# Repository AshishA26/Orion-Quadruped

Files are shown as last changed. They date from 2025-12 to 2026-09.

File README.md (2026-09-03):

# Orion — ROS2 Quadruped Robot

A custom-built 12-DOF quadruped robot designed, built, and programmed from scratch over 8 months. Uses an NVIDIA Jetson Orin Nano for high-level AI and perception, and a custom STM32 PCB for real-time low-level control.

Check out the [Demo Video](https://youtu.be/wUXvWBjLTyA)!

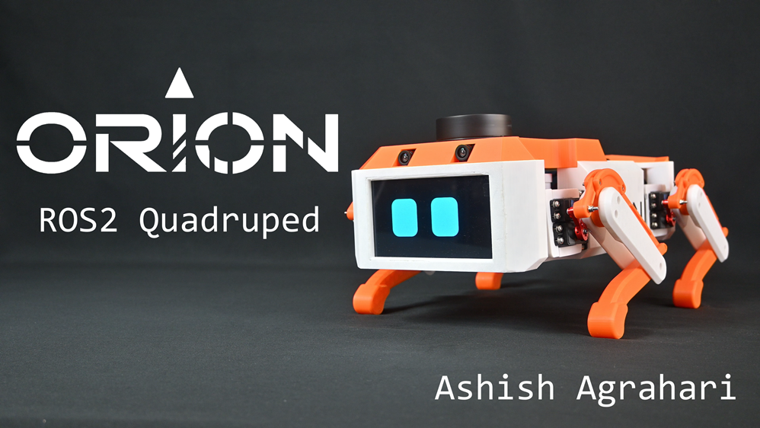
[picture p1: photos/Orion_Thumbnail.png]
Orion


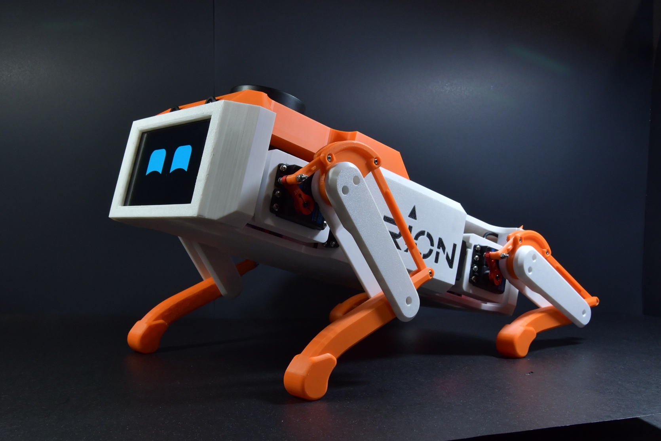
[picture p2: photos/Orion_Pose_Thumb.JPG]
Orion Pose


## Key Features

- **ROS2 / AI** — Isaac ROS Docker on Jetson Orin Nano, TensorRT for accelerated inference
- **Perception** — Stereo depth (MIDAS, SGBM) via dual CSI cameras + MediaPipe hand-pose recognition
- **SLAM & Autonomy** — RPLIDAR A1M8 with `slam_toolbox` and `nav2` for mapping and point-and-click pure-pursuit navigation
- **Embedded Control** — Custom STM32 FreeRTOS firmware: IK, walking gaits, IMU-based stabilization
- **Custom PCBs** — Multi-layer SMD boards for power distribution, servo actuation, and sensor interfacing
- **RL / Sim** — PPO training (RSL RL) in NVIDIA Isaac Lab, flat and rough terrain environments
- **Robot Eyes** — Expressive OLED eye animations via a custom Python/OpenCV node

---

## Software Architecture

**[Jetson — Isaac ROS Workspace](./Software/Jetson/workspace/isaac_ros-dev/README.md)**

| Package | Description |
|:---|:---|
| `orion_base` | STM32 UART bridge, joystick parser, command mux, robot eyes, joint state republisher |
| `orion_camera` | Dual CSI GStreamer node, MIDAS/SGBM depth, MediaPipe hand pose |
| `orion_lidar` | RPLIDAR A1M8 driver, `slam_toolbox` |
| `orion_navigation` | `nav2`, Pure-Pursuit path following |
| `orion_bringup` | Launch files, Docker config, systemd auto-start |
| `orion_msgs` | Custom messages: motion cmd, eye cmd, battery voltage, IMU, leg info |
| `orion_urdf` | URDF model with SolidWorks meshes, RViz launch |

**[STM32](./Software/STM32Firmware/README.md) · [Orion Firmware](./Software/STM32Firmware/Orion/README.md)**

- 5 FreeRTOS tasks: Real-time IK & gait control (Realtime) with 3-DOF per leg and 6-DOF body posture control, UART RX/TX with Jetson via DMA (High/Normal), IMU reading, Battery monitoring.

**[Reinforcement Learning](./Software/reinforcement-learning/README.md)**

- PPO training in Isaac Lab with flat and rough terrain environments. 
- SolidWorks → URDF → USD pipeline.

---

### Software Gallery

| LiDAR SLAM | Autonomous Navigation |
| :---: | :---: |
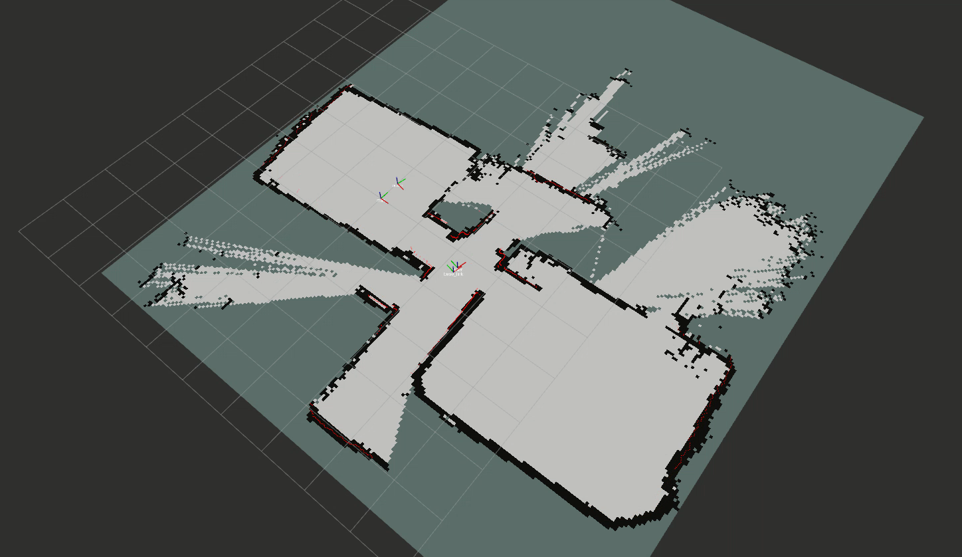
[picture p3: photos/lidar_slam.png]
SLAM
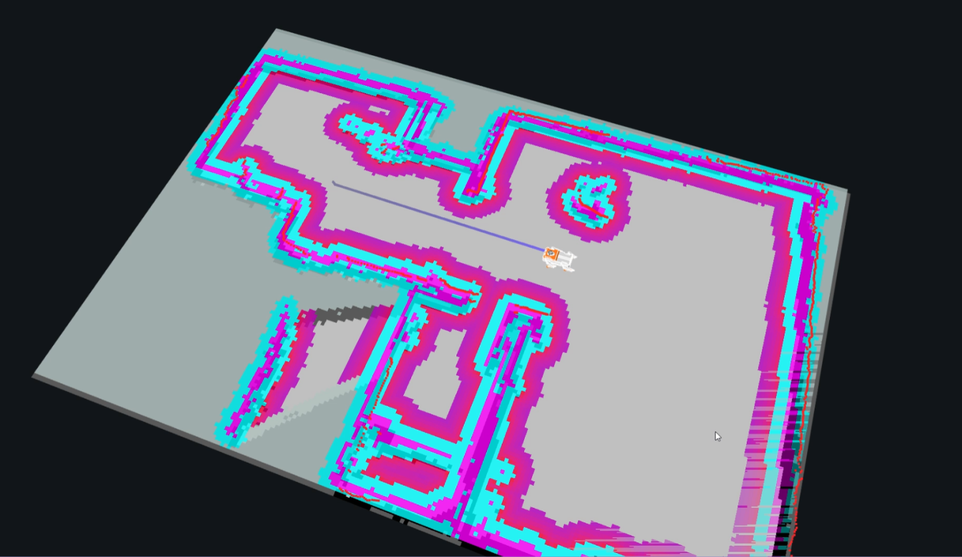
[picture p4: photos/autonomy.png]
Autonomy
|  |  |
| Original Camera Feed | TensorRT Depth Map |
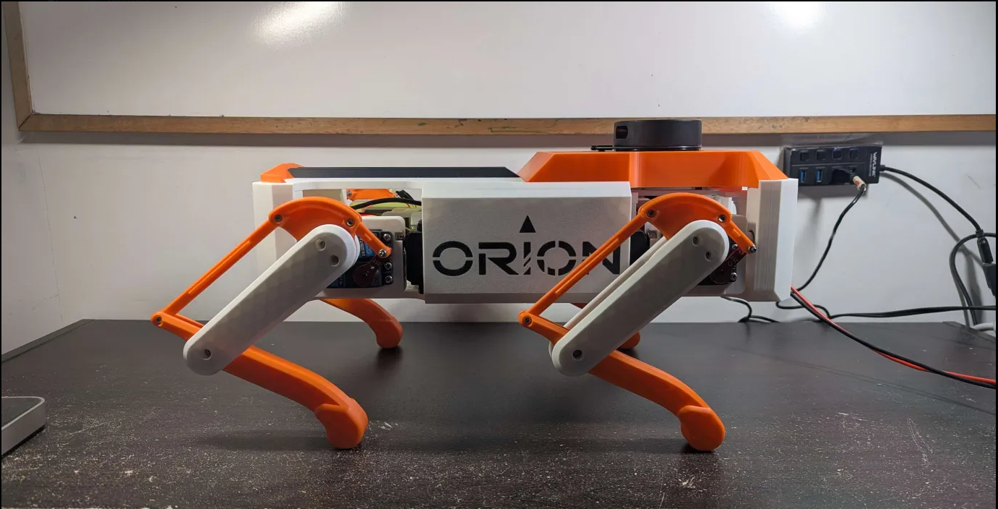
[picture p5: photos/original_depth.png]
Original Image
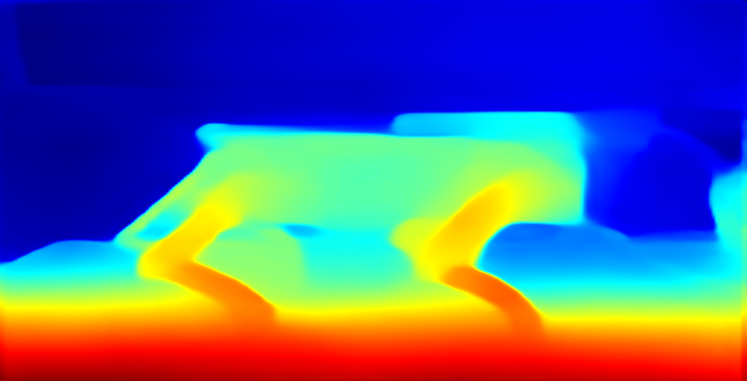
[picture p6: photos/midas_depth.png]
Depth Map
|  |  |
| Hand Pose Detection | Reinforcement Learning in Isaac Lab |
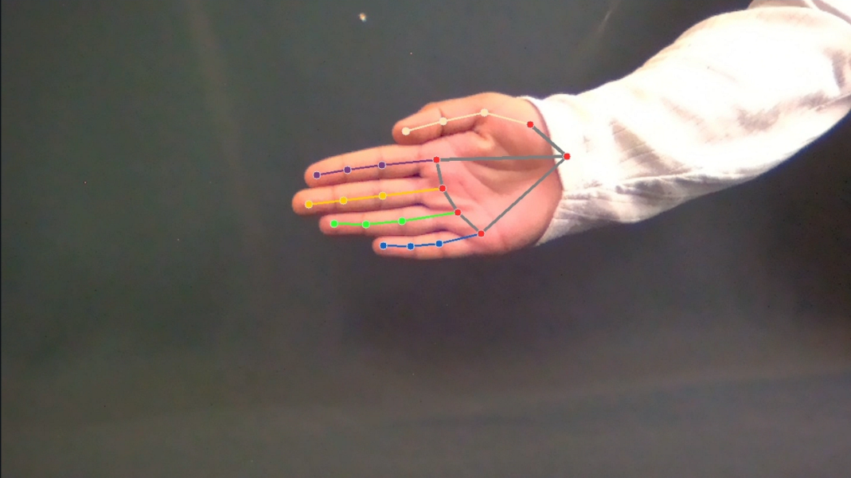
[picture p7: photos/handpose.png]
Hand Pose Recognition
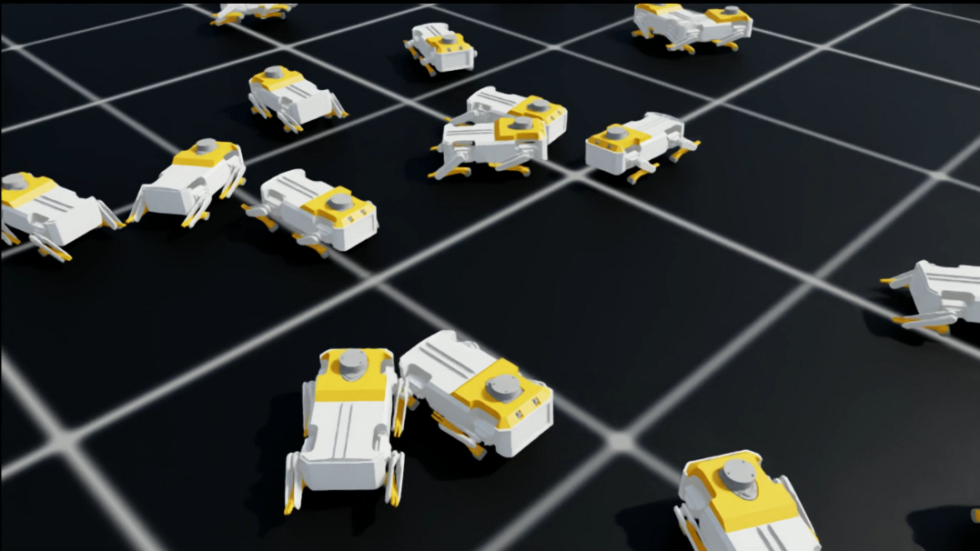
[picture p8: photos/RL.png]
Reinforcement Learning
|  |  |

<p align="center">
    <strong>Foxglove Dashboard</strong>
</p>

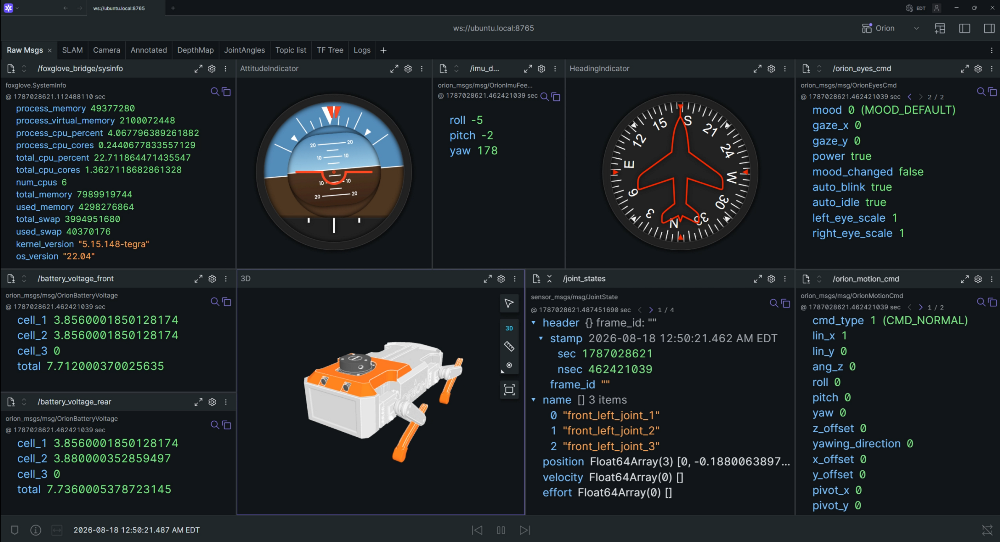
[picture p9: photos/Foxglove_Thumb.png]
Foxglove Dashboard


---

## Electrical & Electronics

Custom multi-layer KiCad PCBs, fully SMD-assembled. Multiple I2C buses with LTC4311 active termination, extensive test pads and debug headers.

- **Control Board** — STM32F401, BNO055 IMU, PCA9685 servo driver
- **Power Board** — Battery distribution, INA3221 voltage monitoring (3 rails), high-current servo lines, battery alarm

### Electrical Gallery
| Control Board | Power Board |
| :---: | :---: |
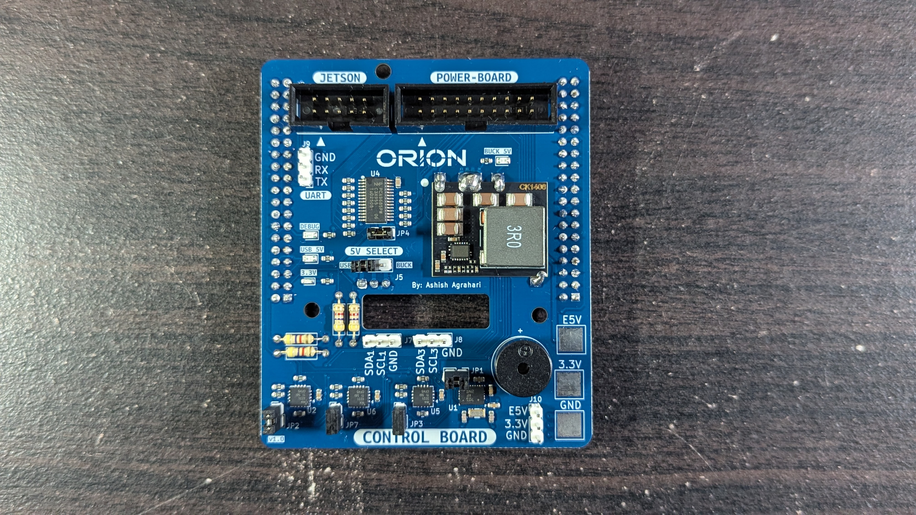
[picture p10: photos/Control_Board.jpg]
Control board
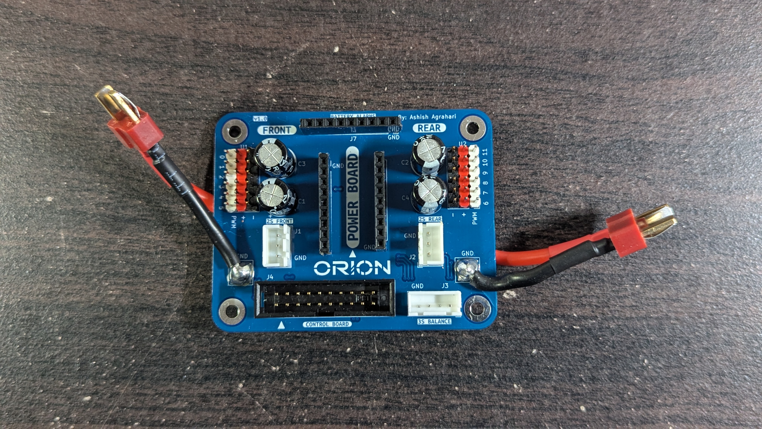
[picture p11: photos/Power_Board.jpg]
Power board
|  |  |

| Control Board | Control Board Compute | Power Board |
| :---: | :---: | :---: |
| Control board schematic | Compute schematic | Power Board schematic |

---

## Mechanical Design

Chassis iteratively modelled in SolidWorks. 3D printed with 2-part silicone injection-molded feet. Bearings in all 12 joints. Magnetic mounts for tool-free access to internal electronics. Single-leg linear-rail test jig used to validate IK and gait before full integration.

| Main body parts | Leg Assembly & Silicone Feet |
| :---: | :---: |
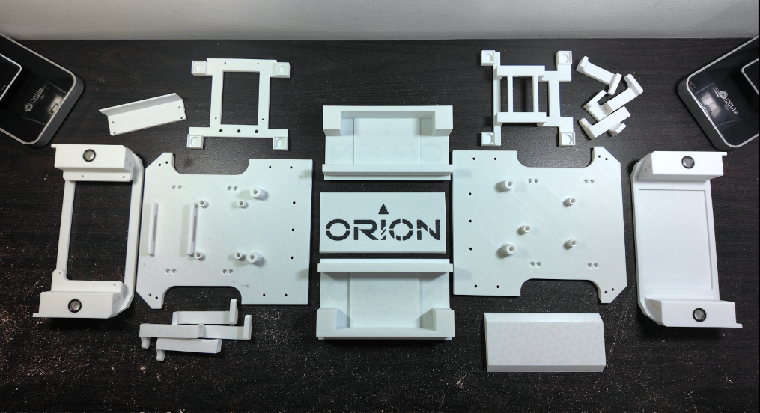
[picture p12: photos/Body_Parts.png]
Body Parts
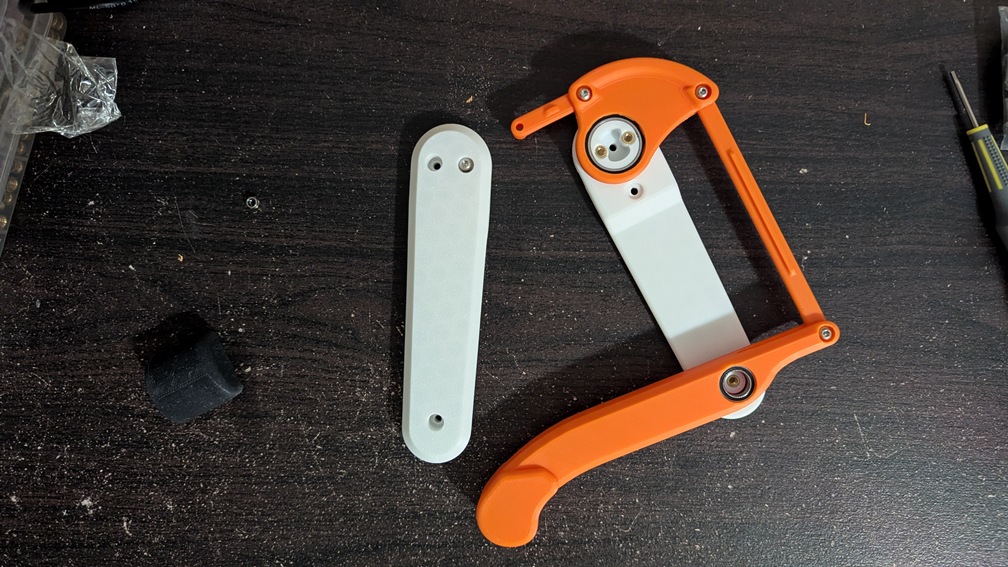
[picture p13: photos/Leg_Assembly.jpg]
Leg Assembly
|  |  |
| Inside Orion (Jetson + PCBs + Display only) | Inside Orion (including Batteries + Lidar + Cameras) |
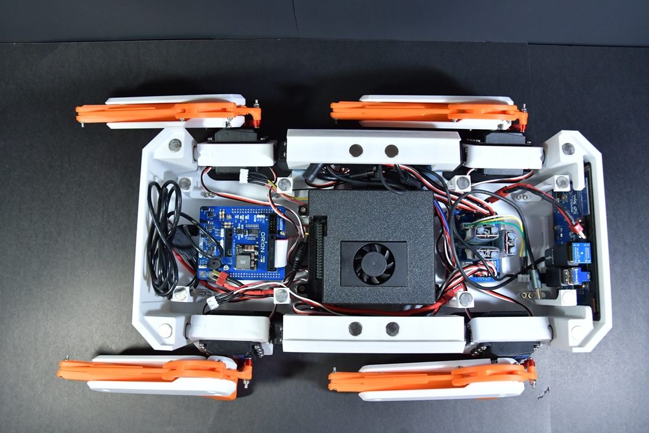
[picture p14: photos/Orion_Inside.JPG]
Orion_Inside
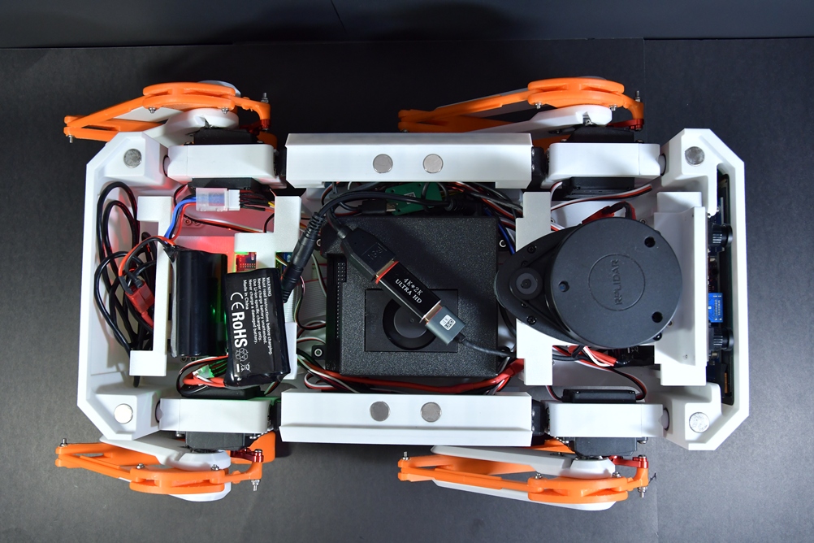
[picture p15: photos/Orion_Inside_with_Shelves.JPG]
Orion_Inside_with_Shelves
|  |  |

---

## Repository Structure
Important directories:
```
Quadruped/
├── Software/
│   ├── Jetson/workspace/isaac_ros-dev/   # Isaac ROS Docker workspace (ROS2 packages)
│   ├── STM32Firmware/
│   │   ├── Orion/                        # Main FreeRTOS firmware (CMake + STM32CubeIDE)
│   │   └── Orion-Controls/               # Legacy PlatformIO firmware
│   ├── reinforcement-learning/           # Isaac Lab PPO training
│   ├── TestScripts/                      # Servo calibration, camera, depth mapping tests
├── models/                               # SolidWorks parts & assemblies, STL, 3MF exports → README
├── urdf/                                 # URDF iterations (ROS2, RL variants) → README
├── pcb/                                  # KiCad projects (Control Board, Power Board) → README
```

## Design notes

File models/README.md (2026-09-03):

# CAD Models
SolidWorks parts and assemblies for Orion's chassis and legs.

## Structure

```
models/
├── Main_Assembly.SLDASM         # Full robot assembly
├── Leg_Assembly_Left.SLDASM     # Left leg sub-assembly
├── Leg_Assembly_Right.SLDASM    # Right leg sub-assembly
├── Foot_Assembly.SLDASM         # Foot + mold assembly
├── *.SLDPRT                     # Individual parts (body panels, femur, tibia, bellcrank, linkages, etc.)
├── STL/                         # 3D print-ready STL exports (32 files)
├── 3mf_Files/                   # 3MF print files
├── linear_rail/                 # Single-leg linear-rail test jig (IK/gait validation)
├── Bearing-tests/               # Bearing fit test prints
└── Electronics/                 # Electronic component models (for assembly reference)
```

## Key Parts

| Part | Description |
|:-----|:---|
| `Body_Bottom`, `Body_Top_Front/Rear`, `Body_Front/Rear`, `Body_side` | Main chassis panels |
| `Femur_Inside`, `Femur_Outside` | Upper leg links |
| `Tibia` | Lower leg link |
| `Bellcrank`, `Linkage_Long`, `Linkage_Short` | 4-bar linkage mechanism for tibia actuation |
| `Leg_servo_holder` | Hip servo mounting bracket |
| `Foot`, `Foot_mold_*` | Foot geometry and 2-part silicone mold |
| `Rear_Shelf`, `Rear_Shelf_Leg` | Internal magnetic shelf components |
| `Camera_Holder`, `Lidar_Camera_Holder`, `Lidar_Holder_Leg` | Sensor mounting hardware |

## Notes

- The `linear_rail/` test jig (`LinearRail.SLDASM`, `WeightTestJig.SLDASM`) was built to validate motor calibration, lifting capacity, IK, and gait before full robot integration.
- Silicone feet use a 2-part mold (`Foot_mold_top_side`, `Foot_mold_bottom_side`) with 2-part silicone injection.

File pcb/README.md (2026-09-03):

# PCB Design Files

KiCad projects for Orion's custom multi-layer PCBs.

## Boards

### [`Orion-Control-Board/`](./Orion-Control-Board/)
Houses compute and sensor interfacing.
- STM32F401 compute module
- BNO055 IMU
- PCA9685 16-channel PWM servo driver (I2C)
- Multiple I2C buses with LTC4311 active termination
- Extensive test pads and debug headers

### [`Orion-Power-Board/`](./Orion-Power-Board/)
Handles all power distribution.
- Raw Li-ion battery input and distribution
- INA3221 triple-channel voltage monitoring (front servos, rear servos, Jetson)
- High-current servo actuation lines
- Battery alarm system

### [`datasheets/`](./datasheets/)
Reference datasheets for key components: STM32F401, BNO055, PCA9685, INA3221, LTC4311, JST eXH connectors, Jetson Orin Nano carrier board, wire ampacity references.

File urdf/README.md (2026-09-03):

# URDF Models

URDF robot description files at various stages of the SolidWorks → ROS2 → Isaac Lab pipeline.

## Structure
URDF Files in this folder are primarily the solidworks models for URDFs, and the exported URDF files from solidworks via the SW2URDF plugin. 

The actual used URDF files can be found in [`Software/reinforcement-learning/src/robot_description`](../Software/reinforcement-learning/src/robot_description) and [`Software/Jetson/workspace/isaac_ros-dev/src/orion_urdf/urdf`](../Software/Jetson/workspace/isaac_ros-dev/src/orion_urdf/urdf). Note these files are different from the ones in this folder and different from each other. Each of these have different modifications for their specific purposes.

```
urdf/
├── models_urdf/           # Soliworks model for ROS2.
├── models_urdf_rl/        # Solidworks model adapted for RL — Added foot joints.
├── orion_urdf_rl/         # Isaac Lab ROS2 package with URDF, meshes, textures, launch
├── urdf_files_original/   # Raw SolidWorks URDF export (v1)
└── urdf_files_original_v2/ # Raw SolidWorks URDF export (v2)
```

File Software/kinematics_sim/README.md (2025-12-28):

# Inverse Kinematics Sim

## Plotting approach

You define the limb lengths (L1,L2,L3) and use your IK equations to calculate joint angles (θ1,θ2,θ3).
You then use Forward Kinematics (FK) to plot the resulting lines.

- `matplotlib_simple_sim`
    - IK sim using matplotlib, assuming knee servo is mounted on femur
    - shows orientation control and choosing center of rotation
    - shows accounting for right vs left leg and 360 degree `atan2`

## PyBullet approach
- You load a URDF file (a 3D model of your robot) and send your IK-calculated angles to the motors.
- It handles gravity and collisions. You'll see if the body drops when the legs move or if the feet slip on the floor.
- `conda install -c conda-forge pybullet`

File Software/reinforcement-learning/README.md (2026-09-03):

# Reinforcement Learning for Orion

PPO reinforcement learning in NVIDIA Isaac Lab for locomotion and potential sim-to-real transfer.

## Registered Environments

| Environment | Terrain | Mode |
|:---|:---|:-----|
| `Isaac-Velocity-Flat-Custom-Quad-v0` | Flat | Train |
| `Isaac-Velocity-Flat-Custom-Quad-Play-v0` | Flat | Play |
| `Isaac-Velocity-Rough-Custom-Quad-v0` | Rough | Train |
| `Isaac-Velocity-Rough-Custom-Quad-Play-v0` | Rough | Play |

## Directory Structure

```
reinforcement-learning/
├── custom_quadruped/        # Isaac Lab environment package
│   ├── custom_quad.py       # Robot articulation config (actuators, init state)
│   ├── flat_env_cfg.py      # Flat terrain env config
│   ├── rough_env_cfg.py     # Rough terrain env config
│   ├── agents/              # RSL RL + SKRL PPO agent configs
│   └── robot.usd            # USD model reference
├── src/                     # Training scripts
└── quadruped.usd            # Standalone USD model
```

---

## Isaac Sim Setup

### Links 
Used:
- [Installation using Isaac Sim Pip Package](https://isaac-sim.github.io/IsaacLab/main/source/setup/installation/pip_installation.html)
- [Step by Step Walkthrough: Installing Isaac Sim and Isaac Lab on Windows](https://www.youtube.com/watch?v=R7zUlsUfdYk)
- [Import Your Robots From URDF to USD - Isaac Sim Tutorial](https://www.youtube.com/watch?v=AMfEtZ4hyLY)
- [URDF Importer Extension](https://docs.isaacsim.omniverse.nvidia.com/4.5.0/robot_setup/ext_isaacsim_asset_importer_urdf.html)
- [Using the Interactive Scene](https://isaac-sim.github.io/IsaacLab/main/source/tutorials/02_scene/create_scene.html)

Other Links:
- [Direct Workflow - Isaac Lab Tutorial 3 (Reinforcement Learning](https://www.youtube.com/watch?v=gdIJ_FcYXvM&list=PLQQ577DOyRN_hY6OAoxBh8K5mKsgyJi-r&index=8)
- [Importing a New Asset](https://isaac-sim.github.io/IsaacLab/main/source/how-to/import_new_asset.html)
- [Tutorial: Import URDF](https://docs.isaacsim.omniverse.nvidia.com/4.5.0/robot_setup/import_urdf.html)

### Commands
```bash
conda create -n env_isaaclab python=3.11
conda activate env_isaaclab
pip install --upgrade pip
pip install "isaacsim[all,extscache]==5.1.0" --extra-index-url https://pypi.nvidia.com
pip install -U torch==2.7.0 torchvision==0.22.0 --index-url https://download.pytorch.org/whl/cu128
isaacsim
git clone git@github.com:isaac-sim/IsaacLab.git
sudo apt install cmake build-essential
cd IsaacLab/
./isaaclab.sh --install

# Testing Isaac Lab
./isaaclab.sh -p scripts/tutorials/00_sim/create_empty.py
./isaaclab.sh -p scripts/tutorials/00_sim/spawn_prims.py 
./isaaclab.sh -p scripts/tutorials/00_sim/create_empty.py
./isaaclab.sh -p scripts/tutorials/02_scene/create_scene.py 
./isaaclab.sh -p scripts/tutorials/03_envs/create_quadruped_base_env.py 
./isaaclab.sh -p scripts/tutorials/02_scene/create_scene.py 
```

### Tip 1
Isaac Sim and Lab are very graphics card dependent and may give errors if you don't have the proper drivers. Ensure you have the correct drivers by doing the following (this also fixes an issue where an HDMI connected monitor does not get displayed on Ubuntu - https://askubuntu.com/questions/1105332/external-monitor-not-working-ubuntu-nvidia):

```bash
sudo prime-select nvidia
sudo ubuntu-drivers autoinstall
reboot
```

That might work only temporarily. Then do `prime-select query` to ensure it says `nvidia`. Then log out, and log in, but choose Ubuntu on Xorg on the bottom right of your screen.

### Tip 2
Expect random glitches and try:
- Restart isaac lab / sim
- Restart machine
- Reinstall drivers / dependencies

## Preprocessing URDF Steps
Before training, I:

1. Added a foot joint (for touch sensor in isaac lab)
2. Exported the urdf from solidworks

Based on [How to Train a Custom Quadruped Robot to Walk Using Isaac Lab](https://www.youtube.com/watch?v=z62oU4hM1xM) mostly, I:

3. Changed the links and joint names to match what is needed
4. Fixed the limits to be non-360 degrees
5. Imported into isaacsim to get the usd file
6. Put usd file and configuration folder into `custom_quadruped`

## Training
### Links
Robot Mania:
- [Channel](https://www.youtube.com/@robotmania8896/videos)
- [How to Train a Custom Quadruped Robot to Walk Using Isaac Lab](https://www.youtube.com/watch?v=z62oU4hM1xM) - primary tutorial used
- [Path Tracking Algorithm Simulation in ROS2](https://www.youtube.com/watch?v=uls-WmxRiTw)
- [Object detection using Yolo3D with ROS2](https://www.youtube.com/watch?v=KTCtTLwJXP0)
- [Training a Quadruped Robot to Walk on a Rough Terrain Using Depth Camera](https://www.youtube.com/watch?v=RaBPTD19Xoc)

Other Links:
- [How We Train Humanoid Robots](https://www.youtube.com/watch?v=oRymQyooWjE)
- [Training Quadrupeds with Reinforcement Learning Reddit](https://www.reddit.com/r/reinforcementlearning/comments/1ik7dhn/training_quadrupeds_with_reinforcement_learning/)
- [Training & Registering Robots - Isaac Lab Tutorial 4 (Reinforcement Learning)](https://www.youtube.com/watch?v=BSQEYj3Wm0Q&list=PLQQ577DOyRN_hY6OAoxBh8K5mKsgyJi-r&index=11)

### Steps
1. Copy the `custom_quadruped` folder to `~/IsaacLab/source/isaaclab_tasks/isaaclab_tasks/manager_based/locomotion/velocity/config/`
2. Then:
```bash
conda activate env_isaaclab
cd ~/Isaaclab/scripts/reinforcement-learning/rsl_rl
python train.py --task=Isaac-Velocity-Flat-Custom-Quad-v0 --num_envs=128 # train
python play.py --task=Isaac-Velocity-Flat-Custom-Quad-v0 --num_envs=16 # play the trained model
```
3. Tensorboard can be viewed by install Tensorboard extension in vscode, then doing `ctrl + shift + P`, and selecting the `~/Isaaclab/scripts/reinforcement-learning/rsl_rl` folder.
4. Tune parameters as needed in the `custom_quadruped` folder. Can add override commands as well.

To stop Processor 0 from heating up, add `--headless` to the train command and switch to `power save` mode instead of `performance`.

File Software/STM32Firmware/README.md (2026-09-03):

# STM32 Firmware for Orion

Custom STM32F401 firmware for Orion's real-time low-level control.

## Projects

### [`Orion/`](./Orion/) — Main Firmware
FreeRTOS firmware with CMake + STM32CubeIDE. Handles IK, gaits, IMU stabilization, and UART comms with the Jetson. → [Detailed README](./Orion/README.md)

### [`Orion-Controls/`](./Orion-Controls/) — Legacy
Earlier PlatformIO-based firmware from initial development. Superseded by `Orion/`.

---

## Setup

- Install [CMake](https://cmake.org/download/)
- Install VSCode extension: `STM32CubeIDE for VSCode`

## Initial Project Configuration
- Create a Project using `STM32CubeMX`.     
    - Set project type to "CMake"
- Open generated folder in VSCode
- Then follow STM32 Extension's guide:
    - In the STM32 Extension, click `Setup STM32Cube Project(s)`

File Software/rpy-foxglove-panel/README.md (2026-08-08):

# RPY Visualization Panel for Foxglove Studio

A custom Foxglove Studio panel extension for visualizing Roll, Pitch, and Yaw (RPY) orientation data with circular gauges.

## Features

- **Three Side-by-Side Circular Gauges**: Visual representation of Roll, Pitch, and Yaw angles
- **Aerospace Color Coding**: Red (Roll/X), Green (Pitch/Y), Blue (Yaw/Z)
- **Real-time Updates**: Subscribes to ROS topics for live data visualization
- **Clear Numerical Displays**: Shows exact angle values in degrees
- **Range: -180° to +180°**: Industry-standard angle representation with zero at top
- **Lightweight & Fast**: Custom SVG-based rendering with no heavy dependencies
- **Topic Selection**: Easy dropdown to select from available ROS topics

## Installation

### Prerequisites

- [Foxglove Studio](https://foxglove.dev/download) installed
- Node.js 16+ and npm

### Build from Source

1. Clone or navigate to this directory:
   ```bash
   cd rpy-panel
   ```

2. Install dependencies:
   ```bash
   npm install
   ```

3. Build the extension:
   ```bash
   npm run build
   ```

4. Package the extension (creates a `.foxe` file):
   ```bash
   npm run package
   ```

5. Install in Foxglove Studio:
   - Open Foxglove Studio
   - Go to Extensions → Install Extension
   - Select the generated `.foxe` file from the `dist` folder

### Development Mode

To develop with hot reload:

```bash
npm run watch
```

Then in Foxglove Studio:
- Go to Extensions → Install Extension
- Navigate to the `rpy-panel` directory and select it

## Usage

### Message Format

Your custom ROS message should contain the following fields:

```
float64 roll   # degrees, -180 to +180
float64 pitch  # degrees, -180 to +180
float64 yaw    # degrees, -180 to +180
```

Example message types that work:
- Custom messages with `roll`, `pitch`, `yaw` fields
- Ensure values are in **degrees** (not radians)

### Using the Panel

1. **Add Panel**: In Foxglove Studio, click the "+" button and select "RPY Visualization"

2. **Select Topic**: Use the dropdown at the top of the panel to select your ROS topic containing RPY data

3. **View Data**: The three gauges will update in real-time as messages arrive:
   - **Roll** (Red): Left gauge
   - **Pitch** (Green): Middle gauge
   - **Yaw** (Blue): Right gauge

### Interpreting the Gauges

- **Zero Position**: Top of each gauge (12 o'clock) represents 0°
- **Clockwise**: Positive angles rotate clockwise
- **Counter-clockwise**: Negative angles rotate counter-clockwise
- **Range Markers**: Major ticks every 90° (-180°, -90°, 0°, +90°)
- **Numeric Display**: Large number below each gauge shows the exact value

## Configuration

### Customizing Colors

Edit `src/RPYPanel.tsx` and modify the `colors` object:

```typescript
const colors = {
  roll: "#EF4444",   // Red - change to your preferred color
  pitch: "#10B981",  // Green
  yaw: "#3B82F6",    // Blue
};
```

### Adjusting Gauge Size

In `src/RPYPanel.tsx`, modify the `size` prop:

```typescript
<CircularGauge
  value={rpyData.roll}
  label="Roll"
  color={colors.roll}
  size={220}  // Change this value (default: 220px)
/>
```

### Handling Different Message Schemas

If your message has a different structure (e.g., nested fields), modify the message extraction logic in `src/RPYPanel.tsx`:

```typescript
// Example for nested structure
const roll = msg.orientation?.roll ?? 0;
const pitch = msg.orientation?.pitch ?? 0;
const yaw = msg.orientation?.yaw ?? 0;
```

## Troubleshooting

### No Data Appearing

1. **Check Topic**: Ensure you've selected the correct topic from the dropdown
2. **Verify Message Format**: Use Foxglove's raw message viewer to confirm your message contains `roll`, `pitch`, `yaw` fields
3. **Check Units**: This panel expects degrees, not radians. If your data is in radians, multiply by `180 / Math.PI`

### Gauge Not Updating

1. **Playback**: Ensure your data source is playing (not paused)
2. **Message Rate**: Check that messages are being published to the topic
3. **Browser Console**: Open Developer Tools (F12) to check for errors

### Converting from Quaternions or Euler Radians

If your data comes as quaternions or radians, you'll need to add conversion logic in `RPYPanel.tsx`:

```typescript
// Example: Convert radians to degrees
const roll = (msg.roll * 180 / Math.PI);
const pitch = (msg.pitch * 180 / Math.PI);
const yaw = (msg.yaw * 180 / Math.PI);
```

## Project Structure

```
rpy-panel/
├── src/
│   ├── RPYPanel.tsx       # Main panel component with subscription logic
│   ├── CircularGauge.tsx  # Reusable SVG gauge component
│   ├── index.ts           # Extension registration
│   └── types.ts           # TypeScript interfaces
├── package.json           # Dependencies and scripts
├── tsconfig.json          # TypeScript configuration
└── README.md              # This file
```

## Development

### Building

```bash
npm run build
```

### Packaging

```bash
npm run package
```

Creates a `.foxe` file in the `dist` directory that can be shared and installed.

### Testing

```bash
npm run pretest
```

## License

MIT

## Support

For issues or questions:
- Check Foxglove Studio documentation: https://docs.foxglove.dev/
- Review the Extension API: https://docs.foxglove.dev/docs/visualization/extensions/getting-started

## Credits

Built with the Foxglove Studio Extension SDK.

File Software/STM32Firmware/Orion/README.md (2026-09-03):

# Orion Firmware

FreeRTOS firmware for the STM32F401 handling all real-time control.

## FreeRTOS Tasks

| Task | Priority | Description |
|:-----|:---|:---|
| `controlTask` | Realtime | IK, gait execution, body posture, IMU-based stabilization |
| `rxCommTask` | High | DMA UART RX — parses packed binary commands from Jetson |
| `txCommTask` | Normal | Sends telemetry to Jetson (IMU, battery voltages, joint angles) |
| `batteryTask` | Low+1 | Polls INA3221 for 3-rail battery voltages |
| `imuTask` | Low | Reads BNO055 orientation (roll, pitch, yaw) |

Shared state protected by `cmdMutex`, `imuMutex`, and `batteryMutex`. FreeRTOS automatic priority inheritance prevents priority inversion.

## Command Protocol (Jetson → STM32)

48-byte packet received over UART at up to 100 Hz via DMA:

| Bytes | Fields | Description |
|:---|:---|:---|
| 0–1 | `0xAA 0x55` | Frame header |
| 2 | `cmd_type` (u8) | `NORMAL`, `RESET`, `WAVE`, `HEEL`, `DANCE`, `EXTRAS`, `EYES`, `BOOTUP` |
| 3–6 | `lin_x` | Linear velocity X (float) |
| 7–10 | `lin_y` | Linear velocity Y (float) |
| 11–14 | `ang_z` | Angular velocity Z / yaw rate (float) |
| 15–18 | `roll` | Body roll offset (float, degrees) |
| 19–22 | `pitch` | Body pitch offset (float, degrees) |
| 23–26 | `yaw` | Body yaw offset (float, degrees) |
| 27–30 | `z_offset` | Body height offset (float, mm) |
| 31–34 | `x_offset` | Body forward translation (float, mm) |
| 35–38 | `y_offset` | Body lateral translation (float, mm) |
| 39–42 | `pivot_x` | Rotation pivot X (float) |
| 43–46 | `pivot_y` | Rotation pivot Y (float) |
| 47 | XOR checksum | XOR over payload bytes 2–46 |

## Telemetry Protocol (STM32 → Jetson)

99-byte packet sent over UART at 10 Hz via DMA:

| Bytes | Fields | Description |
|:---|:---|:---|
| 0–1 | `0xAA 0x55` | Frame header |
| 2–13 | `roll`, `pitch`, `yaw` | IMU orientation (3 × float, degrees) |
| 14–49 | `bus_voltage_V[0..8]` | INA3221 bus voltages across all 9 channels (9 × float, volts) |
| 50–97 | Joint angles (FL, FR, BL, BR) × (hip, femur, tibia) | 12 joint angles (12 × float, degrees) |
| 98 | XOR checksum | XOR over all payload bytes (bytes 2–97) |

## Key Source Files

| File | Description |
|:-----|:---|
| `freertos.c` | Task definitions, DMA UART parser, command dispatch, telemetry TX |
| `LegIK.c/h` | 3-DOF per-leg IK — hip, femur, tibia angles from Cartesian foot position |
| `BodyIK.c/h` | 6-DOF body posture — translation + roll/pitch/yaw with configurable pivot |
| `LegMotion.c/h` | Gait algorithms (trot, wave, sine step), servo actuation, pose definitions |
| `ServoConfig.h` | Per-servo calibrated center offsets and PCA9685 channel mappings |
| `imu.c/h` | BNO055 IMU driver |
| `ina3221.c/h` | INA3221 triple-channel voltage monitor driver |
| `pca9685.c/h` | PCA9685 16-channel PWM servo driver |

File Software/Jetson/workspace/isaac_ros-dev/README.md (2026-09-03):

# Isaac ROS Workspace

ROS2 workspace running on the NVIDIA Jetson Orin Nano inside an Isaac ROS Docker container.

## ROS2 Packages

### `orion_base`
Core system nodes.

| Node | Description |
|:-----|:---|
| `stm32_bridge_node` | Bidirectional UART bridge to STM32 — sends motion commands, receives IMU/battery/joint telemetry |
| `joystick_parser_node` | Parses joystick input into motion and eye commands |
| `cmd_mux_node` | Multiplexes joystick and autonomous navigation commands |
| `roboeyes_node` | OLED eye animations via Python/OpenCV, controlled over ROS2 topics |
| `joint_state_republisher` | Republishes STM32 joint angles as standard `JointState` messages |

### `orion_camera`
| Node | Description |
|:-----|:---|
| `gstreamer_dual_camera_node` | Dual CSI (IMX219) capture via GStreamer |
| `depth_map_node` | MIDAS depth inference with TensorRT |
| `hand_pose_node` | MediaPipe hand gesture recognition |

### `orion_lidar`
- RPLIDAR A1M8 driver — publishes `/scan` for SLAM and navigation.
- `slam_toolbox` for 2D SLAM.
- `rf2o` for laser odometry

### `orion_navigation`
- `nav2` for costmap creation and pure-pursuit path following.

### `orion_bringup`
- Main `bringup.launch.py`.

### `orion_msgs`
- Custom messages: `OrionMotionCmd`, `OrionEyesCmd`, `OrionBatteryVoltage`, `OrionImuFeedback`, `OrionLegInfo`.

### `orion_urdf`
- Full URDF with SolidWorks-exported STL meshes.

### `submodules/`
- `isaac_ros_common`
- `isaac_ros_argus_camera`
- `rf2o_laser_odometry`

## Directory Structure

```
isaac_ros-dev/
├── src/                  # ROS2 packages (see above)
├── scripts/
│   ├── build_robot.sh    # Colcon build
│   ├── run_robot.sh      # Launch with auto display detection
│   ├── autostart.sh      # Systemd entry point
│   └── foxglove-layouts/ # Foxglove dashboard layouts
└── models/
    ├── midas_v21_small_256.onnx   # MIDAS ONNX model
    └── midas_v21_small_256.plan   # TensorRT compiled plan
```

---

## Jetson Setup
```bash
cd ${ISAAC_ROS_WS}
cp src/orion_bringup/docker/.isaac_ros_common-config ~/.
# Systemd services
sudo cp src/orion_bringup/services/* /etc/systemd/system/
sudo systemctl daemon-reload
sudo systemctl enable orion-startup.service
sudo systemctl start orion-startup.service
```

### Checking
```bash
sudo systemctl status orion-startup.service
journalctl -b -u orion-startup.service 
journalctl -af -u orion-startup.service 
```

## Building and Running
```bash
cp src/orion_bringup/docker/.isaac_ros_common-config ~/.
cd ${ISAAC_ROS_WS}/src/submodules/isaac_ros_common && ./scripts/run_dev.sh --skip_image_build
./scripts/build_robot.sh
./scripts/run_robot.sh
```

## Notes
### ROS
Creating a package (when inside docker container):
```bash
cd src
ros2 pkg create --build-type ament_python orion_bringup
```

### General
To fix SSH / connectivity issues from no machine or vs-code, ensure you have the right wifi set, and are on MAXN Super power mode.

### Bag Recording

All (no depth):
```bash
ros2 bag record \
  --storage mcap \
  -o orion_run_$(date +%Y%m%d_%H%M%S) \
  /battery_voltage_front \
  /battery_voltage_jetson \
  /battery_voltage_rear \
  /imu_degrees \
  /joint_angles_back_left \
  /joint_angles_back_right \
  /joint_angles_front_left \
  /joint_angles_front_right \
  /left/camera_info \
  /left/image_compressed \
  /left/image_raw \
  /odom \
  /map \
  /scan \
  /global_costmap/costmap \
  /local_costmap/costmap \
  /plan \
  /robot_description \
  /orion_eyes_cmd \
  /orion_motion_cmd \
  /map_metadata \
  /landmarks \
  /slam_toolbox/update \
  /slam_toolbox/scan_visualization \
  /slam_toolbox/graph_visualization \
  /slam_toolbox/feedback \
  /rosout \
  /pose \
  /joy_motion_cmd \
  /joy_eyes_cmd \
  /joy \
  /annotated_image_compressed \
  /foxglove_bridge/sysinfo \
  /tf \
  /tf_static
```

Just cameras (no depth):
```bash
ros2 bag record \
  --storage mcap \
  -o orion_run_$(date +%Y%m%d_%H%M%S) \
  /left/camera_info \
  /left/image_compressed \
  /left/image_raw \
  /annotated_image_compressed
```

Everything but cameras:
```bash
ros2 bag record \
  --storage mcap \
  -o orion_run_$(date +%Y%m%d_%H%M%S) \
  /battery_voltage_front \
  /battery_voltage_jetson \
  /battery_voltage_rear \
  /imu_degrees \
  /joint_angles_back_left \
  /joint_angles_back_right \
  /joint_angles_front_left \
  /joint_angles_front_right \
  /odom \
  /map \
  /scan \
  /global_costmap/costmap \
  /local_costmap/costmap \
  /plan \
  /robot_description \
  /orion_eyes_cmd \
  /orion_motion_cmd \
  /map_metadata \
  /landmarks \
  /slam_toolbox/update \
  /slam_toolbox/scan_visualization \
  /slam_toolbox/graph_visualization \
  /slam_toolbox/feedback \
  /rosout \
  /pose \
  /joy_motion_cmd \
  /joy_eyes_cmd \
  /joy \
  /foxglove_bridge/sysinfo \
  /tf \
  /tf_static
```

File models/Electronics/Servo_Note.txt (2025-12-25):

From bottom of screw hole to top of servo arm for dsservo is 20.3
For sunfounder, it is 20.63

gap between servo holder and front plate is 5.67

since dsservo is a bit less in height, gap would increase by 0.33.

Thus the ridge on the servo holder needs to be  needs to be 5.67 + 0.33 = 6

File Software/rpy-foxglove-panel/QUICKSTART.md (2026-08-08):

# Quick Start Guide

## 🚀 Installation & Setup (5 minutes)

### Step 1: Create the Extension

```bash
# Navigate to your desired directory
# The extension files have already been created in rpy-panel/
cd rpy-panel
```

### Step 2: Install Dependencies

```bash
npm install
```

This will install:
- Foxglove Studio SDK
- React and TypeScript dependencies
- Build tools and linters

### Step 3: Build the Extension

```bash
npm run build
```

This compiles the TypeScript code into a Foxglove-compatible extension.

### Step 4: Package (Optional - for distribution)

```bash
npm run package
```

This creates a `.foxe` file in the `dist/` folder that you can:
- Share with teammates
- Install on other machines
- Version control and distribute

### Step 5: Install in Foxglove Studio

**Option A: Development Mode (Recommended for development)**

1. Open Foxglove Studio
2. Click **Extensions** in the top menu
3. Select **Install Extension**
4. Navigate to `./rpy-panel`
5. Select the entire folder (not individual files)
6. Click **Open**

**Option B: Production Mode (Using .foxe file)**

1. Open Foxglove Studio
2. Click **Extensions** → **Install Extension**
3. Navigate to `rpy-panel/dist/`
4. Select the `.foxe` file
5. Click **Open**

---

## 🎯 Using the Panel

### Step 1: Add the Panel to Your Layout

1. In Foxglove Studio, click the **"+"** button in the layout
2. Search for **"RPY Visualization"**
3. Click to add the panel to your workspace

### Step 2: Select Your Topic

1. Click the dropdown at the top of the panel labeled **"Select RPY Topic"**
2. Choose your ROS topic that contains roll, pitch, and yaw data
3. The panel will auto-detect topics with names containing:
   - `rpy`
   - `orientation`
   - `attitude`

### Step 3: View Real-Time Data

Once you select a topic and play your data source:
- **Roll** (Red gauge, left) shows rotation around X-axis
- **Pitch** (Green gauge, center) shows rotation around Y-axis
- **Yaw** (Blue gauge, right) shows rotation around Z-axis

---

## 📊 Example ROS Message

Your custom ROS message should look like this:

### Message Definition (e.g., `RPYData.msg`)

```
float64 roll    # degrees, range: -180 to +180
float64 pitch   # degrees, range: -180 to +180
float64 yaw     # degrees, range: -180 to +180
```

### Example Publisher (Python)

```python
#!/usr/bin/env python3
import rospy
from your_package.msg import RPYData
import math

def publish_rpy():
    rospy.init_node('rpy_publisher')
    pub = rospy.Publisher('/robot/rpy', RPYData, queue_size=10)
    rate = rospy.Rate(10)  # 10 Hz

    angle = 0.0
    while not rospy.is_shutdown():
        msg = RPYData()
        msg.roll = 30.0 * math.sin(angle)     # Oscillating roll
        msg.pitch = 20.0 * math.cos(angle)    # Oscillating pitch
        msg.yaw = angle * 10.0 % 360 - 180    # Rotating yaw

        pub.publish(msg)
        angle += 0.1
        rate.sleep()

if __name__ == '__main__':
    try:
        publish_rpy()
    except rospy.ROSInterruptException:
        pass
```

---

## 🔧 Development Workflow

### Live Development with Hot Reload

```bash
npm run watch
```

This starts a file watcher that automatically rebuilds when you save changes. Foxglove Studio will hot-reload the extension.

### Making Changes

1. Edit files in `src/`
2. Save (auto-rebuilds with `npm run watch`)
3. Changes appear instantly in Foxglove

### Common Customizations

**Change gauge colors** (src/RPYPanel.tsx:112):
```typescript
const colors = {
  roll: "#FF0000",   // Your custom color
  pitch: "#00FF00",
  yaw: "#0000FF",
};
```

**Adjust gauge size** (src/RPYPanel.tsx:178):
```typescript
<CircularGauge ... size={300} />  // Larger gauges
```

**Handle different message schemas** (src/RPYPanel.tsx:85):
```typescript
// If your message has nested fields
const roll = msg.orientation?.roll ?? 0;
```

---

## ✅ Verify Installation

After installing, you should see:
- ✅ "RPY Visualization" in the panel picker
- ✅ Topic dropdown showing available topics
- ✅ Three circular gauges when data is playing
- ✅ Real-time updates as messages arrive

---

## 🐛 Troubleshooting

### Extension Not Showing Up

```bash
# Rebuild the extension
npm run build

# Check for errors in the build output
# Reinstall in Foxglove Studio
```

### No Data Appearing

1. ✅ Check topic is selected in dropdown
2. ✅ Verify data source is playing (not paused)
3. ✅ Confirm message has `roll`, `pitch`, `yaw` fields
4. ✅ Ensure values are in **degrees** (not radians)

### Converting from Radians

If your data is in radians, modify `src/RPYPanel.tsx`:

```typescript
const roll = (msg.roll * 180 / Math.PI);
const pitch = (msg.pitch * 180 / Math.PI);
const yaw = (msg.yaw * 180 / Math.PI);
```

---

## 📚 Next Steps

- **Customize**: Edit gauge colors, sizes, or layouts
- **Extend**: Add more features like history graphs or alerts
- **Share**: Package as `.foxe` and distribute to your team
- **Contribute**: Add features and share improvements

---

## 🆘 Need Help?

- 📖 [Foxglove Extension Docs](https://docs.foxglove.dev/docs/visualization/extensions/)
- 💬 [Foxglove Slack Community](https://foxglove.dev/slack)
- 🐛 [Report Issues](https://github.com/foxglove/studio/issues)

Happy visualizing! 🎉

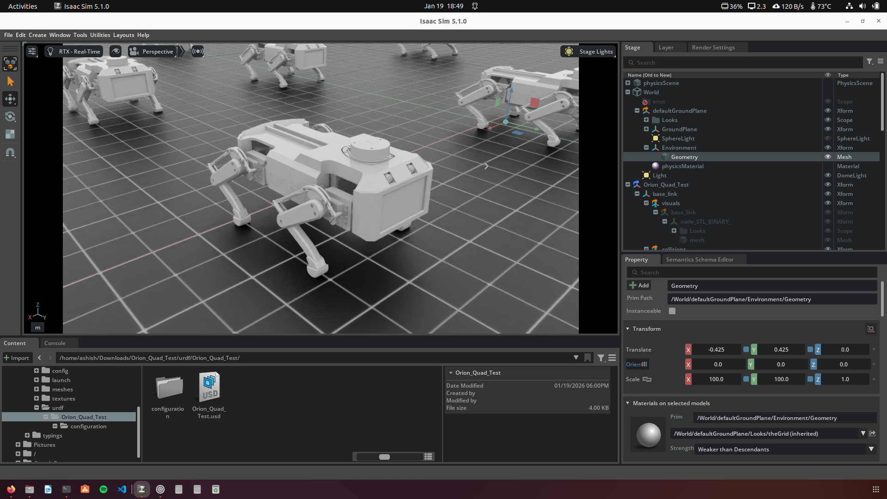
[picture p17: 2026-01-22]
photos/Isaac_Lab.png

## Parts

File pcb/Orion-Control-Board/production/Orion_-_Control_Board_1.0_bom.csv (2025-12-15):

Designator | Footprint | Quantity | Value | LCSC Part #
C1, C2, C4, C8, C9 | 0603 | 5 | 100nF | C14663
C3 | 0603 | 1 | 1uF | C15849
C5, C6 | 0603 | 2 | 22pF | C1653
C7 | 0603 | 1 | 10uF | C96446
D1 | 0805 | 1 | Buck 5V | C2297
D2 | 0603 | 1 | STM32 3.3V | C2286
D3 | 0805 | 1 | DEBUG | C2296
D4 | 0805 | 1 | USB 5V | C2297
R1, R13, R14, R15, R16, R17, R2, R22, R23, R24, R25, R3, R4 | 0603 | 13 | 10k | C25804
R10, R11, R12, R18, R19, R20, R21, R5, R6, R7, R8, R9 | 0603 | 12 | 220 | C22962
R26, R35 | 0603 | 2 | 470 | C23179
R28, R31 | 0603 | 2 | 75 | C4275
U1 | LGA-28_5.2x3.8mm_P0.5mm | 1 | BNO055 | C93216
U2, U5, U6 | Texas_RGV0016A_VQFN-16-1EP_4x4mm_P0.65mm_EP2.1x2.1mm_ThermalVias | 3 | INA3221 | C181255
U4 | TSSOP-28_4MM | 1 | PCA9685_PWM_SERVO_DRIVER_IC | C2678753
Y1 | CRYSTAL-SMD-3.2X1.5MM | 1 | 32.768 kHz | C97606

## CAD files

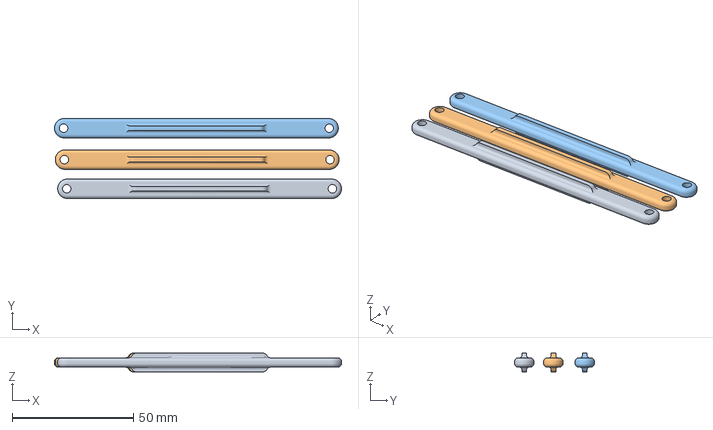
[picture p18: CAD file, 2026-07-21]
models/3mf_Files/Long_Linkages.3mf
118.3 x 33.0 x 7.80 mm
Linkage_Long.STL x 3

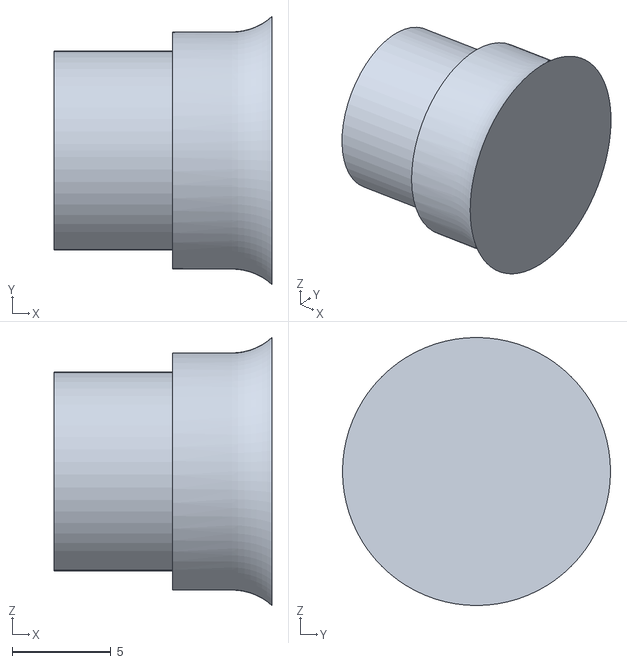
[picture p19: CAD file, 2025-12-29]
models/Bearing-tests/Leg_servo_holder_Pt2_Test.STL
11.0 x 13.6 x 13.6

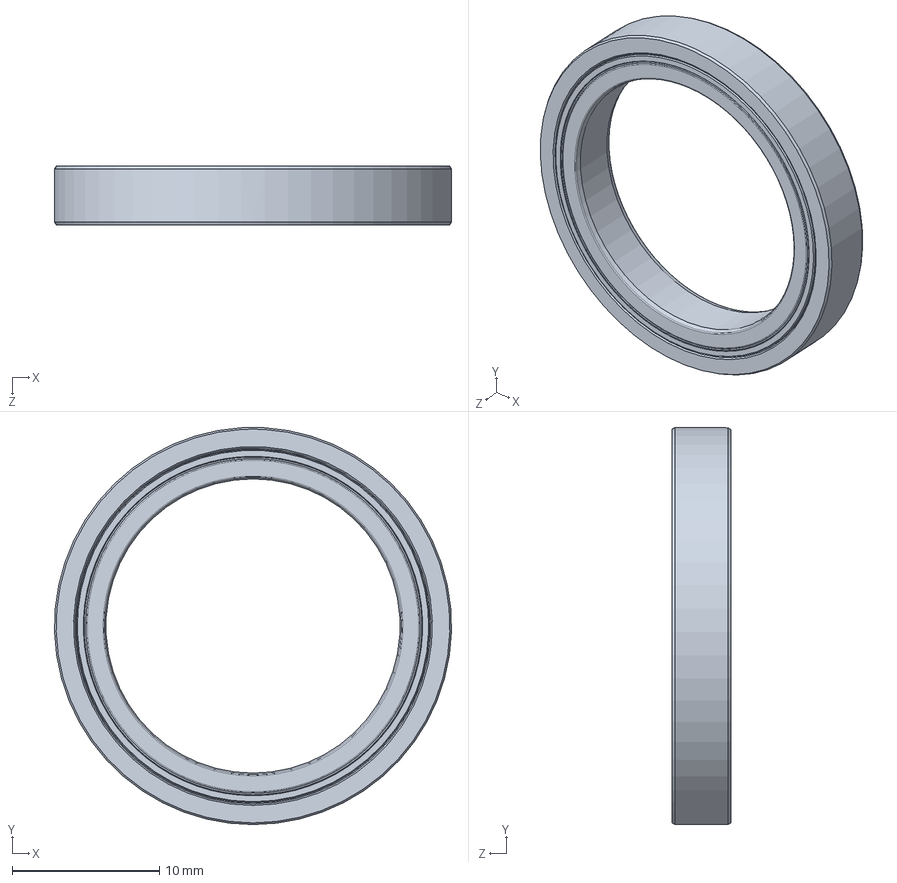
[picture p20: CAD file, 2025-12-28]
models/Electronics/Bearing_6704-2RS_20x27x4.SLDPRT
27.0 x 27.0 x 4.00 mm

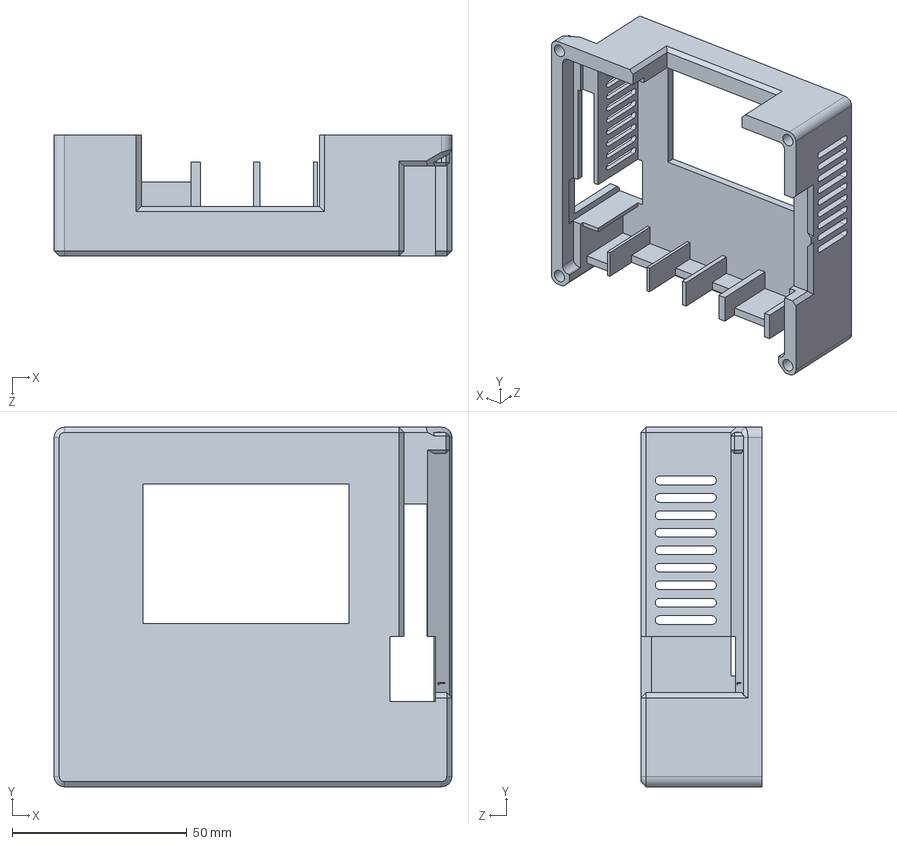
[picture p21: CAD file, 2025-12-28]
models/Electronics/Jetson/Case-Top.SLDPRT
114.0 x 103.0 x 34.8 mm

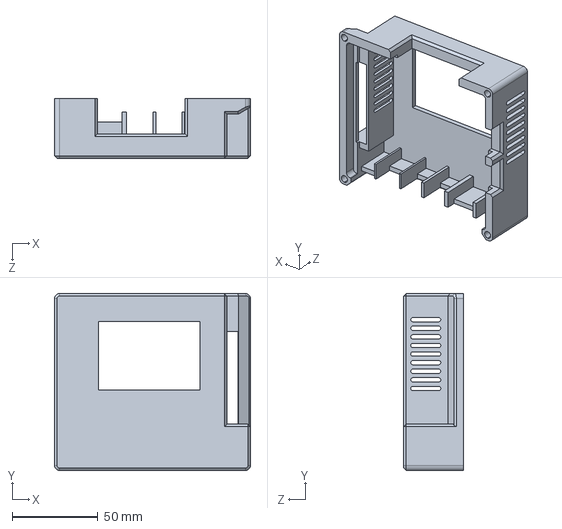
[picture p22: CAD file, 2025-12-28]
models/Electronics/Jetson/Original/Jetson_Orin_Nano_DevKit_Case-Top - Original.SLDPRT
114.0 x 103.0 x 34.8 mm

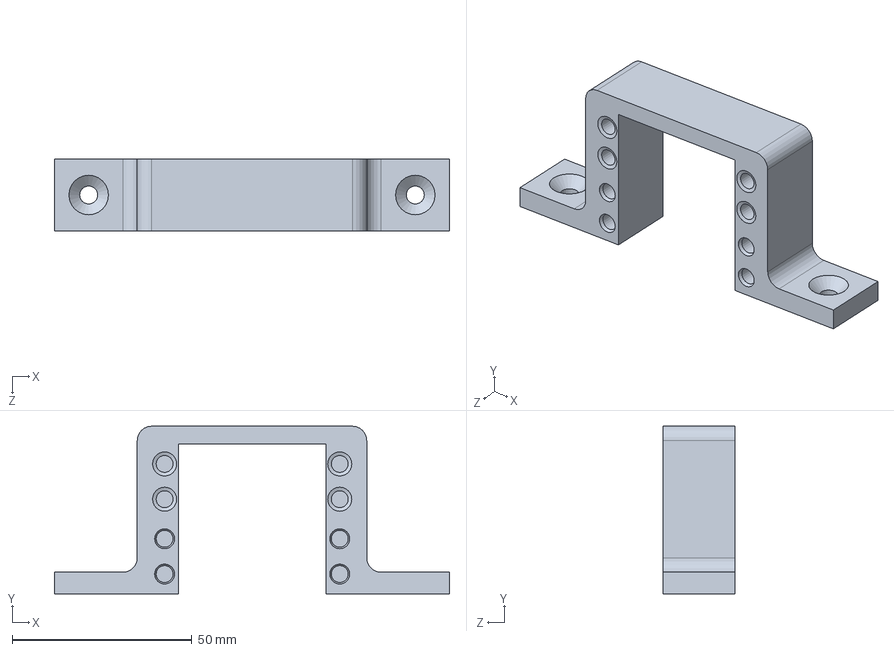
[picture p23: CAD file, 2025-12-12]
models/linear_rail/ServoMount.SLDPRT
109.8 x 46.6 x 20.0 mm

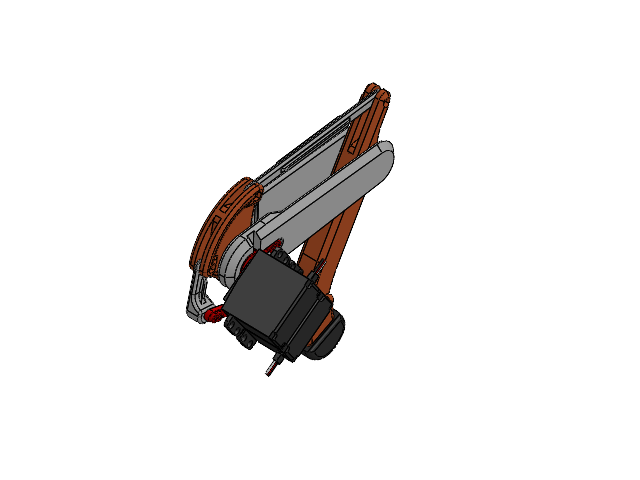
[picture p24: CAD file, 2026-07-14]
models/Leg_Assembly_Right.SLDASM
Tibia
Bellcrank
servo_arm_25T x 2
sunfounder_20kg_sized_for_dsservo x 2
Linkage_Long
Foot
Femur_Outside
Femur_Inside
Linkage_Short
Bearing_6700-2RS_10x15x4 x 2
Bearing_6704-2RS_20x27x4

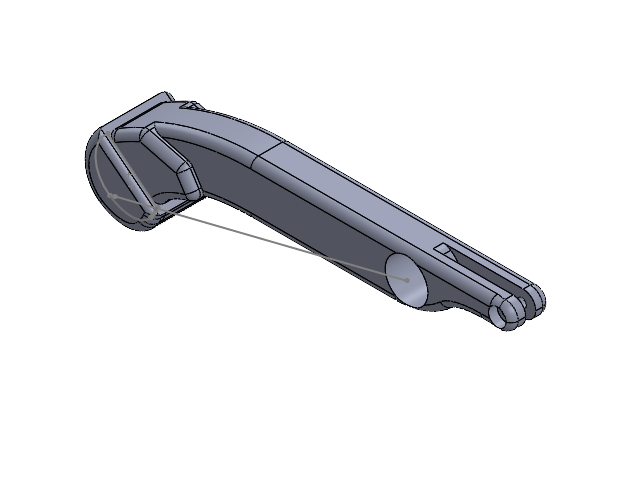
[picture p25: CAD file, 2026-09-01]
urdf/models_urdf_rl/Foot_Assembly.SLDASM
Foot
Tibia_for_mold

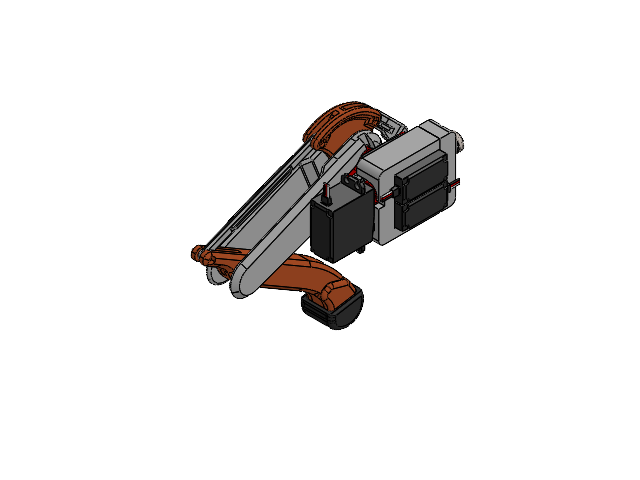
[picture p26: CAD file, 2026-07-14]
models/Leg_Assembly_Isolated.SLDASM
Femur_Inside
Femur_Outside
Tibia
Bellcrank
servo_arm_25T x 3
sunfounder_20kg_sized_for_dsservo x 3
Linkage_Long
Linkage_Short
Foot
Leg_servo_holder
Bearing_6704-2RS_20x27x4
Bearing_6700-2RS_10x15x4 x 3

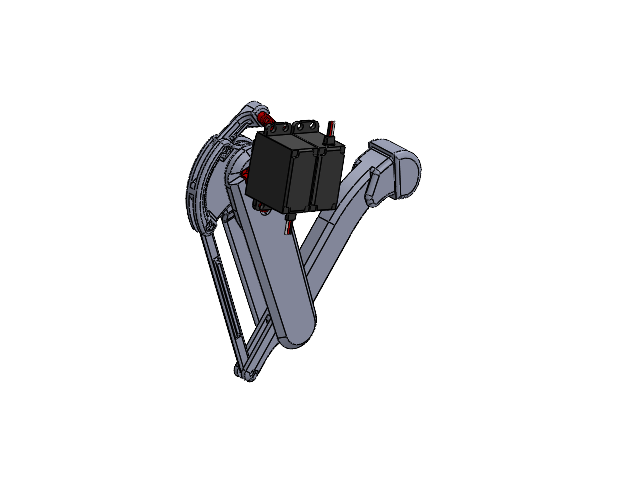
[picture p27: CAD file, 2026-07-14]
models/Leg_Assembly_Left.SLDASM
Bearing_6700-2RS_10x15x4 x 2
Bearing_6704-2RS_20x27x4
Foot
Linkage_Long
sunfounder_20kg_sized_for_dsservo x 2
servo_arm_25T x 2
Bellcrank
Tibia
Femur_Outside
Femur_Inside
Linkage_Short

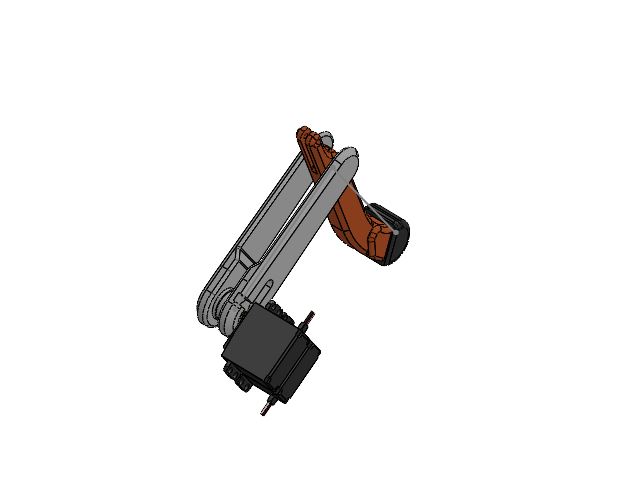
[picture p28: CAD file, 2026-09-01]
urdf/models_urdf_rl/Leg_Assembly_Right.SLDASM
Tibia
sunfounder_20kg_sized_for_dsservo x 2
Foot
Femur_Outside
Femur_Inside

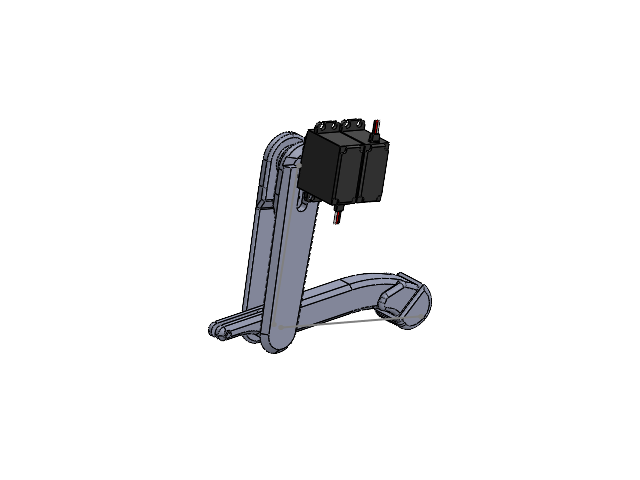
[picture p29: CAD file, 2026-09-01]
urdf/models_urdf_rl/Leg_Assembly_Left.SLDASM
Foot
sunfounder_20kg_sized_for_dsservo x 2
Tibia
Femur_Outside
Femur_Inside

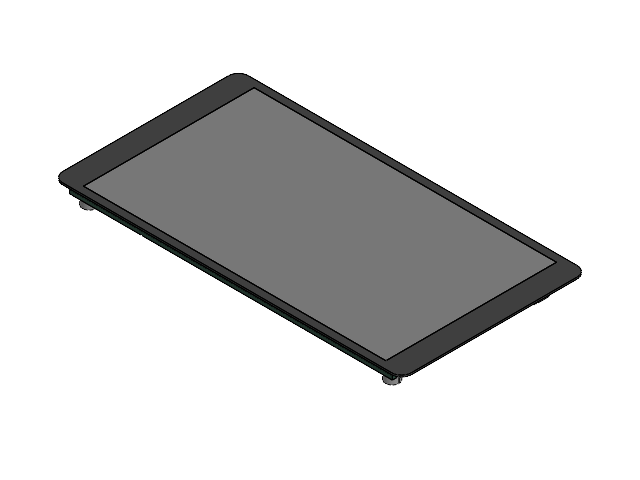
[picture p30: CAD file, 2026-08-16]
urdf/models_urdf_rl/Electronics/5_5inch-hdmi-amoled.SLDASM
SOLID-775_1.stp x 66
COMPOUND-3334_1.stp
COMPOUND-95598_1.stp x 2
SOLID-186524_1.stp x 5
COMPOUND-188553_1_1.stp
COMPOUND-188553_2_1.stp
COMPOUND-188553_3_1.stp
COMPOUND-188553_4_1.stp
COMPOUND-188553_ASM_1_ASM-0.stp
SOLID-191743_1.stp x 8
SOLID-196629_1.stp x 72
SOLID-198653_1.stp x 2
SOLID-204981_1.stp
SOLID-271627_1.stp
SOLID-284667_1.stp
SOLID-293721_1.stp x 2
SOLID-299144_1.stp x 2
SOLID-306527_1.stp
SOLID-322783_1.stp
SOLID-324870_1.stp
COMPOUND-335936_1.stp
SOLID-462937_1.stp
HL1802_KICAD_V1_0_PCB_2.stp
TP-FPC-01_1.stp
J1_CUI_DEVICES_SJ2-35894D-SMT_2.stp
J1_CUI_DEVICES_SJ2-35894D-SMT_3.stp
J1_CUI_DEVICES_SJ2-35894D-SMT_4.stp
SMTSO-M2_5-4ET_3.stp x 8
EVA_1_1.stp
EVA_1_2.stp
EVA_1_3.stp
EVA_1_4.stp
5_5INCH-1440X2560-TP_4.stp
5_5INCH-1440X2560-LCD_3.stp

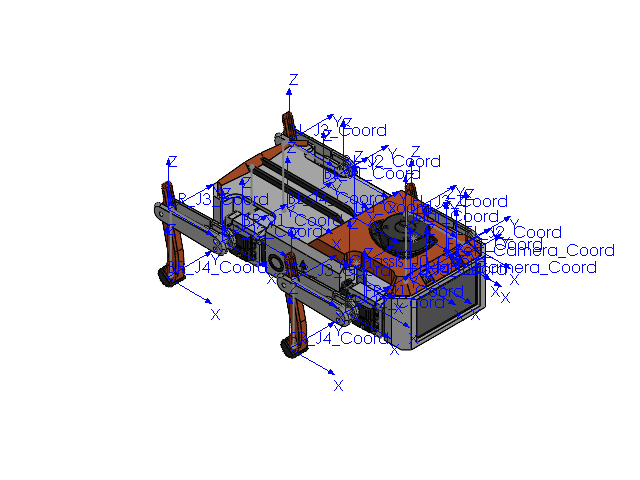
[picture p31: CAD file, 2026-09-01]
urdf/models_urdf_rl/Main_Assembly_Urdf.SLDASM
Foot x 4
sunfounder_20kg_sized_for_dsservo x 12
Tibia x 4
Femur_Outside x 4
Femur_Inside x 4
Leg_servo_holder x 4
Body_side x 2
Body_Front
Body_Top_Front
Body_Top_Rear
Body_Rear
Part1^Main_Assembly_Urdf
5_5inch-hdmi-amoled
RPLIDAR_A1M8
Lidar_Camera_Holder
Lidar_Holder_Leg x 2
Camera_Holder
Camera_Body1
Camera_Body2

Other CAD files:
models/Electronics/Orion-Power-Board.SLDASM
models/Leg_Assembly_Isolated_Kinematics-Sketch.SLDASM
models/Main_Assembly.SLDASM
models/Foot_mold_assembly.SLDASM
Software/Jetson/workspace/isaac_ros-dev/src/orion_urdf/meshes/back_left_link_1.STL
Software/Jetson/workspace/isaac_ros-dev/src/orion_urdf/meshes/back_left_link_2.STL
Software/Jetson/workspace/isaac_ros-dev/src/orion_urdf/meshes/back_left_link_3.STL
Software/Jetson/workspace/isaac_ros-dev/src/orion_urdf/meshes/back_right_link_1.STL
Software/Jetson/workspace/isaac_ros-dev/src/orion_urdf/meshes/back_right_link_2.STL
Software/Jetson/workspace/isaac_ros-dev/src/orion_urdf/meshes/back_right_link_3.STL
Software/Jetson/workspace/isaac_ros-dev/src/orion_urdf/meshes/chassis_link.STL
Software/Jetson/workspace/isaac_ros-dev/src/orion_urdf/meshes/front_left_link_1.STL
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

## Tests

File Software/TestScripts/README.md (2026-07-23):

# Leg Assembly Instructions

1. Power up each servo
1. Use Servo Clocking script to set approx. 135 degrees (270/2)
1. Place Servo arm on Servo, per appropriate orientation (hip vs femur/tibia)
1. Assemble Entire Leg
1. Use Servo Clocking script to finetune i.e. clock position. Record the angle/microseconds needed to put the servo arm in the middle position.
1. This angle will be added in the code for each servo.

# STM32 setup in Arduino IDE:
 - In Arduino IDE, go to File -> Preferences
 - Add this URL to `Additional Board Manager URLs`: https://github.com/stm32duino/BoardManagerFiles/raw/main/package_stmicroelectronics_index.json
 
# Camera Setup
1. ENSURE that the camera cables are connected properly. I am doing from dual camera (imx-219) to jetson orin nano. There is a red light on the camera PCB that should switch on if powered correctly. Options for camera connection are:
	- Use the short wires (1 per camera) that came with the camera, OR
	- Use 3 wires + 2 extension boards per camera. This is the only way I have found so far because the wire needs to be flipped and then flipped again.
2. Do
	```bash
	cd /opt/nvidia/jetson-io/
	sudo python3 jetson-io.py 
	```

3. Set the camera pins to be configured for `Camera IMX219 Dual`. Then do `Save and reboot to reconfigure pins` option
4. `ls /dev/video*` should now should 2 video feeds
5. Now you can run `python3 csi-camera/dual_camera.py` (needs `numpy`, can do `pip3 install numpy`). The `csi-camera` folder is from [JetsonHacks](https://github.com/JetsonHacksNano/CSI-Camera).
6. To fix the pink edges (from: [Jonathan Tse](https://jonathantse.medium.com/fix-pink-tint-on-jetson-nano-wide-angle-camera-a8ce5fbd797f))

	```bash
	sudo cp camera-config/camera_overrides.isp /var/nvidia/nvcam/settings/
	sudo chmod 664 /var/nvidia/nvcam/settings/camera_overrides.isp
	sudo chown root:root /var/nvidia/nvcam/settings/camera_overrides.isp
	```

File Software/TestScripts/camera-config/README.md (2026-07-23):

# Camera Config Settings

Fix the pink borders: 
- https://wiki.seeedstudio.com/how_to_use_camera_imx219/
- https://jonathantse.medium.com/fix-pink-tint-on-jetson-nano-wide-angle-camera-a8ce5fbd797f

```bash
sudo cp camera_overrides.isp /var/nvidia/nvcam/settings/
sudo chmod 664 /var/nvidia/nvcam/settings/camera_overrides.isp
sudo chown root:root /var/nvidia/nvcam/settings/camera_overrides.isp
```

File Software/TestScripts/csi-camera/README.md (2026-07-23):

# CSI-Camera
From https://github.com/JetsonHacksNano/CSI-Camera.

Simple example of using a MIPI-CSI(2) Camera (like the Raspberry Pi Version 2 camera) with the NVIDIA Jetson Developer Kits with CSI camera ports. This includes the recent Jetson Nano and Jetson Xavier NX.  This is support code for the article on JetsonHacks: https://wp.me/p7ZgI9-19v

For the Nanos and Xavier NX, the camera should be installed in the MIPI-CSI Camera Connector on the carrier board. The pins on the camera ribbon should face the Jetson module, the tape stripe faces outward.

Some Jetson developer kits have two CSI camera slots. You can use the sensor_mode attribute with the GStreamer nvarguscamerasrc element to specify which camera. Valid values are 0 or 1 (the default is 0 if not specified), i.e.

```
nvarguscamerasrc sensor_id=0
```

To test the camera:

```
# Simple Test
#  Ctrl^C to exit
# sensor_id selects the camera: 0 or 1 on Jetson Nano B01
$ gst-launch-1.0 nvarguscamerasrc sensor_id=0 ! nvoverlaysink

# More specific - width, height and framerate are from supported video modes
# Example also shows sensor_mode parameter to nvarguscamerasrc
# See table below for example video modes of example sensor
$ gst-launch-1.0 nvarguscamerasrc sensor_id=0 ! \
   'video/x-raw(memory:NVMM),width=1920, height=1080, framerate=30/1' ! \
   nvvidconv flip-method=0 ! 'video/x-raw,width=960, height=540' ! \
   nvvidconv ! nvegltransform ! nveglglessink -e
```

Note: The cameras may report differently than show below. You can use the simple gst-launch example above to determine the camera modes that are reported by the sensor you are using. 
```
GST_ARGUS: 1920 x 1080 FR = 29.999999 fps Duration = 33333334 ; Analog Gain range min 1.000000, max 10.625000; Exposure Range min 13000, max 683709000;
```

Also, the display transform may be sensitive to width and height (in the above example, width=960, height=540). If you experience issues, check to see if your display width and height is the same ratio as the camera frame size selected (In the above example, 960x540 is 1/4 the size of 1920x1080).

## Samples

### simple_camera.py
simple_camera.py is a Python script which reads from the camera and displays the frame to a window on the screen using OpenCV:
```
$ python simple_camera.py
```
### face_detect.py

face_detect.py is a python script which reads from the camera and uses  Haar Cascades to detect faces and eyes:
```
$ python face_detect.py
```
Haar Cascades is a machine learning based approach where a cascade function is trained from a lot of positive and negative images. The function is then used to detect objects in other images. 

See: https://docs.opencv.org/3.3.1/d7/d8b/tutorial_py_face_detection.html 

### dual_camera.py
Note: You will need install numpy for the Dual Camera Python example to work:
```
$ pip3 install numpy
```
This example is for the newer Jetson boards (Jetson Nano, Jetson Xavier NX) with two CSI-MIPI camera ports. This is a simple Python program which reads both CSI cameras and displays them in one window. The window is 1920x540. For performance, the script uses a separate thread for reading each camera image stream. To run the script:

```
$ python3 dual_camera.py
```

### simple_camera.cpp
The last example is a simple C++ program which reads from the camera and displays to a window on the screen using OpenCV:

```
$ g++ -std=c++11 -Wall -I/usr/lib/opencv -I/usr/include/opencv4 simple_camera.cpp -L/usr/lib -lopencv_core -lopencv_highgui -lopencv_videoio -o simple_camera

$ ./simple_camera
```
This program is a simple outline, and does not handle needed error checking well. For better C++ code, use https://github.com/dusty-nv/jetson-utils

<h2>Notes</h2>

<h3>Camera Image Formats</h3>
You can use v4l2-ctl to determine the camera capabilities. v4l2-ctl is in the v4l-utils:
```
$ sudo apt-get install v4l-utils
```
For the Raspberry Pi V2 camera, a typical output is (assuming the camera is /dev/video0):

```
$ v4l2-ctl --list-formats-ext
ioctl: VIDIOC_ENUM_FMT
	Index       : 0
	Type        : Video Capture
	Pixel Format: 'RG10'
	Name        : 10-bit Bayer RGRG/GBGB
		Size: Discrete 3280x2464
			Interval: Discrete 0.048s (21.000 fps)
		Size: Discrete 3280x1848
			Interval: Discrete 0.036s (28.000 fps)
		Size: Discrete 1920x1080
			Interval: Discrete 0.033s (30.000 fps)
		Size: Discrete 1280x720
			Interval: Discrete 0.017s (60.000 fps)
		Size: Discrete 1280x720
			Interval: Discrete 0.017s (60.000 fps)
```

<h3>GStreamer Parameter</h3>
For the GStreamer pipeline, the nvvidconv flip-method parameter can rotate/flip the image. This is useful when the mounting of the camera is of a different orientation than the default.

```

flip-method         : video flip methods
                        flags: readable, writable, controllable
                        Enum "GstNvVideoFlipMethod" Default: 0, "none"
                           (0): none             - Identity (no rotation)
                           (1): counterclockwise - Rotate counter-clockwise 90 degrees
                           (2): rotate-180       - Rotate 180 degrees
                           (3): clockwise        - Rotate clockwise 90 degrees
                           (4): horizontal-flip  - Flip horizontally
                           (5): upper-right-diagonal - Flip across upper right/lower left diagonal
                           (6): vertical-flip    - Flip vertically
                           (7): upper-left-diagonal - Flip across upper left/low
```

<h2>OpenCV and Python</h2>
Starting with L4T 32.2.1 / JetPack 4.2.2, GStreamer support is built in to OpenCV.
The OpenCV version is 3.3.1 for those versions. Please note that if you are using
earlier versions of OpenCV (most likely installed from the Ubuntu repository), you
will get 'Unable to open camera' errors.
<br>
If you can open the camera in GStreamer from the command line, and have issues opening the camera in Python, check the OpenCV version. 

```
>>>cv2.__version__
```

<h2>Release Notes</h2>

v3.2 Release January, 2022
* Add Exception handling to Python code
* Faster GStreamer pipelines, better performance
* Better naming of variables, simplification
* Remove Instrumented examples
* L4T 32.6.1 (JetPack 4.5)
* OpenCV 4.4.1
* Python3
* Tested on Jetson Nano B01, Jetson Xavier NX
* Tested with Raspberry Pi V2 cameras

v3.11 Release April, 2020
* Release both cameras in dual camera example (bug-fix)

v3.1 Release March, 2020
* L4T 32.3.1 (JetPack 4.3)
* OpenCV 4.1.1
* Tested on Jetson Nano B01
* Tested with Raspberry Pi v2 cameras

v3.0 December 2019
* L4T 32.3.1
* OpenCV 4.1.1.
* Tested with Raspberry Pi v2 camera

v2.0 Release September, 2019
* L4T 32.2.1 (JetPack 4.2.2)
* OpenCV 3.3.1
* Tested on Jetson Nano

Initial Release (v1.0) March, 2019
* L4T 32.1.0 (JetPack 4.2)
* Tested on Jetson Nano

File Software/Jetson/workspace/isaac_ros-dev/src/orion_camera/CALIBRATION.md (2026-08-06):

# IMX219-83 Stereo Camera Calibration Guide

This guide walks through calibrating both cameras on the IMX219-83 dual CSI module using a checkerboard pattern. Since the IMX219-83 has **no EEPROM**, calibration data must be generated manually and saved to YAML files.

## Prerequisites

- A printed checkerboard pattern (recommended: 9×6 inner corners, 25mm squares)
  - Print on rigid cardboard — do not use a screen
  - Measure the actual square size after printing (printers often scale)
- ROS 2 camera calibration package:
  ```bash
  sudo apt-get install ros-humble-camera-calibration
  ```

## Step 1: Start the Camera Node

Use either the GStreamer or Isaac ROS Argus solution to publish camera images:

```bash
# Option A: GStreamer (simpler, no Isaac container needed)
ros2 launch orion_camera gstreamer_camera.launch.py

# Option B: Isaac ROS Argus (inside Isaac ROS container)
ros2 launch orion_camera camera.launch.py
```

Verify images are publishing:
```bash
ros2 topic list | grep image_raw
# Should show:
#   /left/image_raw
#   /right/image_raw
```

## Step 2: Calibrate the Left Camera

Run the calibration tool pointing at the left camera topics:

```bash
ros2 run camera_calibration cameracalibrator \
  --size 8x5 \
  --square 0.025 \
  --no-service-check \
  image:=/left/image_raw \
  camera:=/left
```

> **Note**: `--size` is inner corners (columns-1 x rows-1). For a 9×6 checkerboard, use `8x5`.

- Move the checkerboard slowly through the camera's field of view
- Cover all edges and corners of the image
- Tilt the board at various angles
- The calibration bars (X, Y, Size, Skew) should all turn green
- Click **CALIBRATE** when all bars are green
- Click **SAVE** to export the calibration data
- Click **COMMIT** if available

The calibration file is saved to `/tmp/calibrationdata.tar.gz`. Extract it:

```bash
cd /tmp && tar xzf calibrationdata.tar.gz
# The YAML file is at: /tmp/ost.yaml
```

Copy it to the camera config:
```bash
cp /tmp/ost.yaml $(ros2 pkg prefix orion_camera)/share/orion_camera/config/left_camera_info.yaml
# Or copy to the source tree:
cp /tmp/ost.yaml src/orion_camera/config/left_camera_info.yaml
```

## Step 3: Calibrate the Right Camera

Repeat the same process for the right camera:

```bash
ros2 run camera_calibration cameracalibrator \
  --size 8x5 \
  --square 0.025 \
  --no-service-check \
  image:=/right/image_raw \
  camera:=/right
```

Save and copy to `right_camera_info.yaml`.

## Step 4: Verify Calibration

After copying both calibration files, restart the camera node and check that `CameraInfo` messages contain the correct values:

```bash
ros2 topic echo /left/camera_info --once
ros2 topic echo /right/camera_info --once
```

You can also visually verify with `rqt_image_view`:
```bash
ros2 run rqt_image_view rqt_image_view
```

## Calibration File Format

Both files use the standard ROS camera calibration YAML format:

```yaml
image_width: 1920
image_height: 1080
camera_name: left_camera
camera_matrix:
  rows: 3
  cols: 3
  data: [fx, 0, cx, 0, fy, cy, 0, 0, 1]
distortion_model: plumb_bob
distortion_coefficients:
  rows: 1
  cols: 5
  data: [k1, k2, p1, p2, k3]
rectification_matrix:
  rows: 3
  cols: 3
  data: [1, 0, 0, 0, 1, 0, 0, 0, 1]
projection_matrix:
  rows: 3
  cols: 4
  data: [fx', 0, cx', 0, 0, fy', cy', 0, 0, 0, 1, 0]
```

## Notes

- The approximate IMX219 intrinsics in the placeholder files (fx=fy≈1380 at 1080p) are reasonable starting points but will be off by 5-15% per sensor.
- Each sensor MUST be calibrated individually — manufacturing tolerances mean the two sensors on the IMX219-83 will have slightly different intrinsics.
- If you change the capture resolution, you must re-calibrate.
- For stereo extrinsics (baseline, relative rotation), use `ros2 run camera_calibration cameracalibrator --stereo` with both camera topics simultaneously.

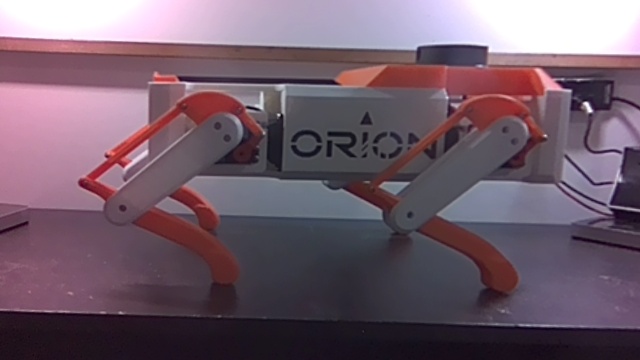
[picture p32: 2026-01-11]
Software/TestScripts/depth_mapping/leftv2.jpeg

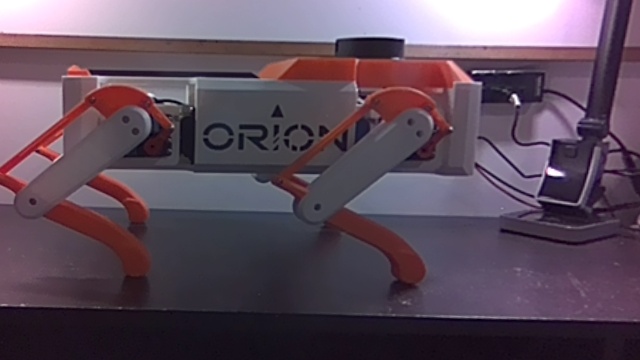
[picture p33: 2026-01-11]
Software/TestScripts/depth_mapping/rightv2.jpeg

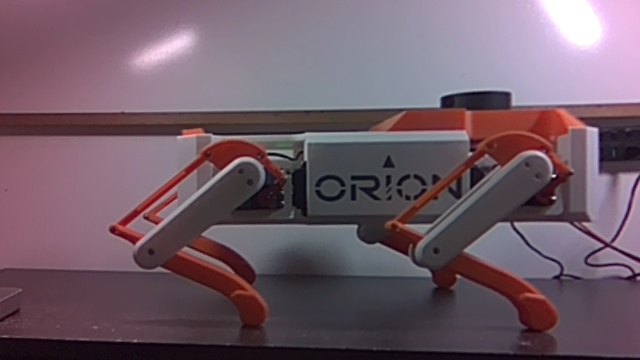
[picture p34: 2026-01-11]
Software/TestScripts/depth_mapping/left.jpeg

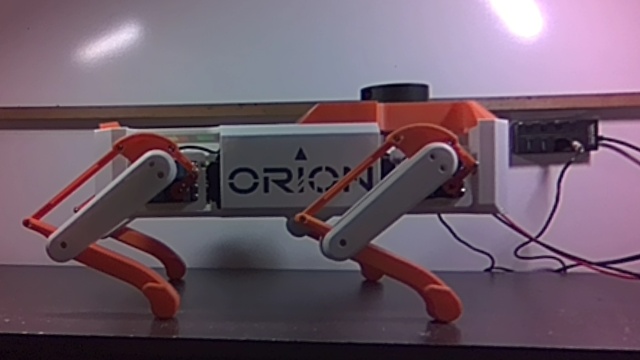
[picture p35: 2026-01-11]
Software/TestScripts/depth_mapping/right.jpeg

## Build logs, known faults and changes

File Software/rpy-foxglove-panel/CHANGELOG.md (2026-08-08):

# Changelog

All notable changes to this project will be documented in this file.

## [1.1.0] - 2026-08-08

### Changed
- **Roll direction corrected**: Rolling right now shows positive values (negated input)
- **Pitch direction corrected**: Pitching up now shows positive values (negated input)
- **Pitch gauge now works like an attitude indicator**:
  - 0° is horizontal at 3 o'clock (horizon reference)
  - +90° at top (nose up)
  - -90° at bottom (nose down)
  - ±180° at left
- **Tick mark labels corrected for standard mode**: 0° at top (12 o'clock), +90° at right (3 o'clock), 180° at bottom (6 o'clock), -90° at left (9 o'clock)
- **Tick mark labels for attitude mode**: 0° at right (horizon), +90° at top (nose up), -90° at bottom (nose down), ±180° at left

### Added
- Attitude indicator mode for pitch visualization
- Mode selector for gauges (standard vs attitude)

## [1.0.0] - 2026-08-08

### Added
- Initial release of RPY Visualization Panel
- Three circular gauges for Roll, Pitch, and Yaw visualization
- Custom SVG-based gauge components with zero dependencies
- Aerospace color coding (Red/Green/Blue for Roll/Pitch/Yaw)
- Topic selection dropdown with auto-detection
- Real-time data updates from ROS messages
- Support for -180° to +180° degree range
- Numeric value displays with exact angles
- Last update timestamp display
- Graceful handling of undefined/null message states
- Proper cleanup of subscriptions on unmount

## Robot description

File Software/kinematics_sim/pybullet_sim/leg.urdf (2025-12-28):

<?xml version="1.0"?>
<robot name="single_leg">

  <link name="base_link">
    <visual>
      <geometry><box size="0.1 0.1 0.1"/></geometry>
      <material name="blue"><color rgba="0 0 1 1"/></material>
    </visual>
  </link>

  <joint name="hip_joint" type="revolute">
    <parent link="base_link"/>
    <child link="coxa_link"/>
    <origin xyz="0 0 0"/>
    <axis xyz="0 0 1"/>
    <limit lower="-1.57" upper="1.57" effort="10" velocity="1"/>
  </joint>

  <link name="coxa_link">
    <visual>
      <origin xyz="0.025 0 0"/>
      <geometry><box size="0.05 0.03 0.03"/></geometry>
    </visual>
  </link>

  <joint name="thigh_joint" type="revolute">
    <parent link="coxa_link"/>
    <child link="femur_link"/>
    <origin xyz="0.05 0 0"/>
    <axis xyz="0 1 0"/>
    <limit lower="-1.57" upper="1.57" effort="10" velocity="1"/>
  </joint>

  <link name="femur_link">
    <visual>
      <origin xyz="0 0 -0.05"/>
      <geometry><box size="0.02 0.02 0.1"/></geometry>
    </visual>
  </link>

  <joint name="knee_joint" type="revolute">
    <parent link="femur_link"/>
    <child link="tibia_link"/>
    <origin xyz="0 0 -0.1"/>
    <axis xyz="0 1 0"/>
    <limit lower="-2.5" upper="0" effort="10" velocity="1"/>
  </joint>

  <link name="tibia_link">
    <visual>
      <origin xyz="0 0 -0.05"/>
      <geometry><box size="0.02 0.02 0.1"/></geometry>
    </visual>
  </link>

</robot>

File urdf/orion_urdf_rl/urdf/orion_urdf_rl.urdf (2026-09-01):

<?xml version="1.0" encoding="utf-8"?>
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
<robot name="orion_urdf_rl">
  <link name="chassis_link">
    <inertial>
      <origin xyz="-0.021069 1.7626E-05 -0.059532" rpy="0 0 0" />
      <mass value="1.2884" />
      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
    </inertial>
    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
  </link>
  <joint name="lid_joint" type="fixed">
    <origin xyz="0.01 0 0.1" rpy="0 0 0" />
    <parent link="chassis_link" />
    <child link="lid_link" />
    <axis xyz="0 0 0" />
  </joint>
  <link name="lidar_link">
    <inertial>
      <origin xyz="-0.011935 0.00030729 -0.023703" rpy="0 0 0" />
      <mass value="0.073251" />
      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
    </inertial>
    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
  </link>
  <joint name="lidar_joint" type="fixed">
    <origin xyz="0.10304797227565 -8.87688453378886E-05 0.0345" rpy="0 0 0" />
    <parent link="chassis_link" />
    <child link="lidar_link" />
    <axis xyz="0 0 0" />
  </joint>
  <link name="left_camera_link">
    <inertial>
      <origin xyz="-0.011101 -0.0048656 -0.0023316" rpy="0 0 0" />
      <mass value="0.0043213" />
      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
    </inertial>
    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
  </link>
  <joint name="left_camera_joint" type="fixed">
    <origin xyz="0.17653 0.02985 -0.00265" rpy="0 0 0" />
    <parent link="chassis_link" />
    <child link="left_camera_link" />
    <axis xyz="0 0 0" />
  </joint>
  <link name="right_camera_link">
    <inertial>
      <origin xyz="-0.011105 0.0048562 -0.0023281" rpy="0 0 0" />
      <mass value="0.0043257" />
      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
    </inertial>
    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
  </link>
  <joint name="right_camera_joint" type="fixed">
    <origin xyz="0.17653 -0.03025 -0.00265" rpy="0 0 0" />
    <parent link="chassis_link" />
    <child link="right_camera_link" />
    <axis xyz="0 0 0" />
  </joint>
  <link name="front_left_link_1">
    <inertial>
      <origin xyz="0.011486 0.0010424 -0.0097839" rpy="0 0 0" />
      <mass value="0.10768" />
      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
    </inertial>
    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
  </link>
  <joint name="front_left_joint_1" type="revolute">
    <origin xyz="0.10379030300648 0.0824500000000001 -0.0540925624189766" rpy="0 0 0" />
    <parent link="chassis_link" />
    <child link="front_left_link_1" />
    <axis xyz="-1 0 0" />
    <limit lower="-3.1416" upper="3.1416" effort="10" velocity="1" />
  </joint>
  <link name="front_left_link_2">
    <inertial>
      <origin xyz="-0.045582 0.00046171 1.378E-05" rpy="0 0 0" />
      <mass value="0.062209" />
      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
    </inertial>
    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
  </link>
  <joint name="front_left_joint_2" type="revolute">
    <origin xyz="0 0.039298 0.000625" rpy="0 0 0" />
    <parent link="front_left_link_1" />
    <child link="front_left_link_2" />
    <axis xyz="0 1 0" />
    <limit lower="-3.1416" upper="3.1416" effort="10" velocity="1" />
  </joint>
  <link name="front_left_link_3">
    <inertial>
      <origin xyz="0.0089822 -3.9694E-06 -0.057845" rpy="0 0 0" />
      <mass value="0.052056" />
      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
    </inertial>
    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
  </link>
  <joint name="front_left_joint_3" type="revolute">
    <origin xyz="-0.1095 0 0" rpy="0 0 0" />
    <parent link="front_left_link_2" />
    <child link="front_left_link_3" />
    <axis xyz="0 -1 0" />
    <limit lower="-3.1416" upper="3.1416" effort="10" velocity="1" />
  </joint>
  <link name="front_left_link_4">
    <inertial>
      <origin xyz="0.0061269 -7.9975E-07 0.0067623" rpy="0 0 0" />
      <mass value="0.0071989" />
      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
    </inertial>
    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
  </link>
  <joint name="front_left_joint_4" type="fixed">
    <origin xyz="-0.00241539800881991 0 -0.119811924362056" rpy="0 0 0" />
    <parent link="front_left_link_3" />
    <child link="front_left_link_4" />
    <axis xyz="0 0 0" />
  </joint>
  <link name="back_left_link_1">
    <inertial>
      <origin xyz="0.0094199 0.0010436 -0.0097838" rpy="0 0 0" />
      <mass value="0.10768" />
      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
    </inertial>
    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
  </link>
  <joint name="back_left_joint_1" type="revolute">
    <origin xyz="-0.144705178168527 0.08275 -0.0540925624189766" rpy="-0.000120278924918832 0 0" />
    <parent link="chassis_link" />
    <child link="back_left_link_1" />
    <axis xyz="1 0 0" />
    <limit lower="-3.1416" upper="3.1416" effort="10" velocity="1" />
  </joint>
  <link name="back_left_link_2">
    <inertial>
      <origin xyz="-0.045582 0.00046171 1.3835E-05" rpy="0 0 0" />
      <mass value="0.062209" />
      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
    </inertial>
    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
  </link>
  <joint name="back_left_joint_2" type="revolute">
    <origin xyz="0 0.0392976651289136 0.000629726685457487" rpy="0 0 0" />
    <parent link="back_left_link_1" />
    <child link="back_left_link_2" />
    <axis xyz="0 1 0" />
    <limit lower="-3.1416" upper="3.1416" effort="10" velocity="1" />
  </joint>
  <link name="back_left_link_3">
    <inertial>
      <origin xyz="0.0089823 -3.8206E-06 -0.057844" rpy="0 0 0" />
      <mass value="0.052055" />
      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
    </inertial>
    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
  </link>
  <joint name="back_left_joint_3" type="revolute">
    <origin xyz="-0.1095 0 0" rpy="0.00012028 0 0" />
    <parent link="back_left_link_2" />
    <child link="back_left_link_3" />
    <axis xyz="0 -1 0" />
    <limit lower="-3.1416" upper="3.1416" effort="10" velocity="1" />
  </joint>
  <link name="back_left_link_4">
    <inertial>
      <origin xyz="0.0061269 -7.9975E-07 0.0067623" rpy="0 0 0" />
      <mass value="0.0071989" />
      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
    </inertial>
    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
  </link>
  <joint name="back_left_joint_4" type="fixed">
    <origin xyz="-0.0024154 0 -0.11981" rpy="0 0 0" />
    <parent link="back_left_link_3" />
    <child link="back_left_link_4" />
    <axis xyz="0 0 0" />
  </joint>
  <link name="back_right_link_1">
    <inertial>
      <origin xyz="0.0094199 -0.0010424 -0.0097839" rpy="0 0 0" />
      <mass value="0.10768" />
      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
    </inertial>
    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
  </link>
  <joint name="back_right_joint_1" type="revolute">
    <origin xyz="-0.144705178168499 -0.08245 -0.0540925624189766" rpy="0 0 0" />
    <parent link="chassis_link" />
    <child link="back_right_link_1" />
    <axis xyz="1 0 0" />
    <limit lower="-3.1416" upper="3.1416" effort="10" velocity="1" />
  </joint>
  <link name="back_right_link_2">
    <inertial>
      <origin xyz="-0.045582 -0.00046171 -1.378E-05" rpy="0 0 0" />
      <mass value="0.062209" />
      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
    </inertial>
    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
  </link>
  <joint name="back_right_joint_2" type="revolute">
    <origin xyz="0 -0.039297740587505 0.000624999999999695" rpy="0 0 0" />
    <parent link="back_right_link_1" />
    <child link="back_right_link_2" />
    <axis xyz="0 -1 0" />
    <limit lower="-3.1416" upper="3.1416" effort="10" velocity="1" />
  </joint>
  <link name="back_right_link_3">
    <inertial>
      <origin xyz="0.0089816 3.7944E-06 -0.057848" rpy="0 0 0" />
      <mass value="0.05206" />
      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
    </inertial>
    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
  </link>
  <joint name="back_right_joint_3" type="revolute">
    <origin xyz="-0.1095 0 0" rpy="0 0 0" />
    <parent link="back_right_link_2" />
    <child link="back_right_link_3" />
    <axis xyz="0 1 0" />
    <limit lower="-3.1416" upper="3.1416" effort="10" velocity="1" />
  </joint>
  <link name="back_right_link_4">
    <inertial>
      <origin xyz="0.0062016 -8.0137E-07 0.0066938" rpy="0 0 0" />
      <mass value="0.0071989" />
      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
    </inertial>
    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
  </link>
  <joint name="back_right_joint_4" type="fixed">
    <origin xyz="-0.00255555314355546 0 -0.119685144101967" rpy="0 0 0" />
    <parent link="back_right_link_3" />
    <child link="back_right_link_4" />
    <axis xyz="0 0 0" />
  </joint>
  <link name="front_right_link_1">
    <inertial>
      <origin xyz="0.011486 -0.0010424 -0.0097839" rpy="0 0 0" />
      <mass value="0.10768" />
      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
    </inertial>
    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
  </link>
  <joint name="front_right_joint_1" type="revolute">
    <origin xyz="0.103790303006509 -0.0827499999999999 -0.0540925624189766" rpy="0 0 0" />
    <parent link="chassis_link" />
    <child link="front_right_link_1" />
    <axis xyz="-1 0 0" />
    <limit lower="-3.1416" upper="3.1416" effort="10" velocity="1" />
  </joint>
  <link name="front_right_link_2">
    <inertial>
      <origin xyz="-0.045582 -0.00046171 -1.378E-05" rpy="0 0 0" />
      <mass value="0.062209" />
      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

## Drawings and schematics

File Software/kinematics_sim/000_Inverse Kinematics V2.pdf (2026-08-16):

# Coordinate System:

Jo | ·

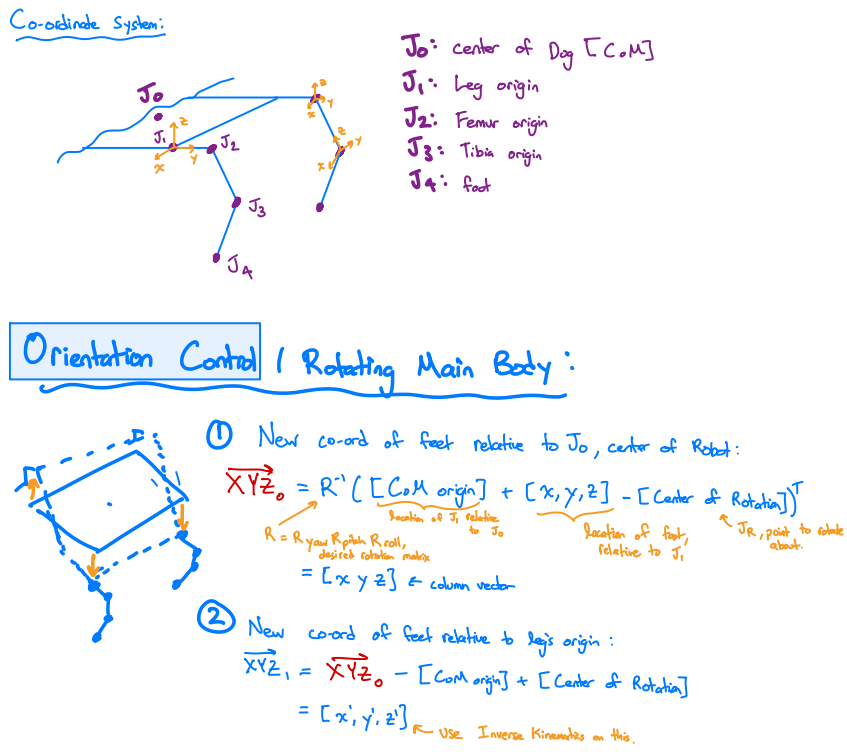
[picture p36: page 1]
Center of Dog [CoM]; 1: Leg origin M⑧; Femur origin; Tibia origin; foot; R" ([Morigi⁺ [x, y, z) -; [Center of; Rotatitis a; location of foot,; desired rotation matrix; relative to J,; [x y z] = column rector; ② New coord of feet relative to leg's origin :; XYz ,; z]a use; Inverse Kinematics on; this

mentation Control/Rotating Main Body :

① New co-ord of feet relative to Jo ,

center of Robot :

JR ,point to rotate
about.

yaw Rpitch Rroll,

[CoMorigin] + [Center of Rotation =

#verse Kinematics : | known : | Foot (end effector) position

| | Y,

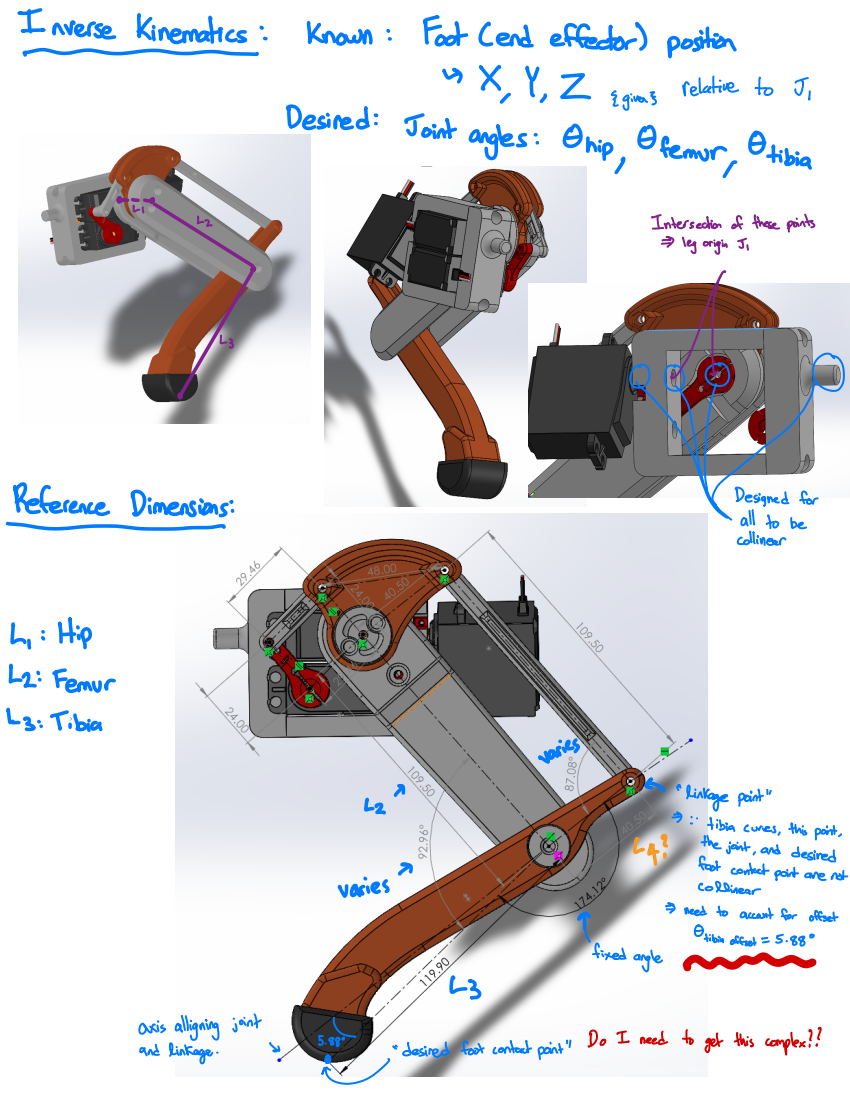
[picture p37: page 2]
relative to J, Egive3; Desired :; Joint angles :; Ghip; Ofemur Otibia; Intersection of these points; => leg origin J I; Reference Dimensions:; L : Hip; Femur; ↳3: Tibia; varies; "linkage point"; =>: tibia curves,; this point,; the joint, and desired -; foot contact point are not; Collinear; => need to account for offset; fixed; Otibia offset = 5.; angle -; axis alligning joint; and linkage.; desired foot contact point" "; Do I need to get this complex ??

Hi Joint : | Back view of front left leg
5 | pivot point

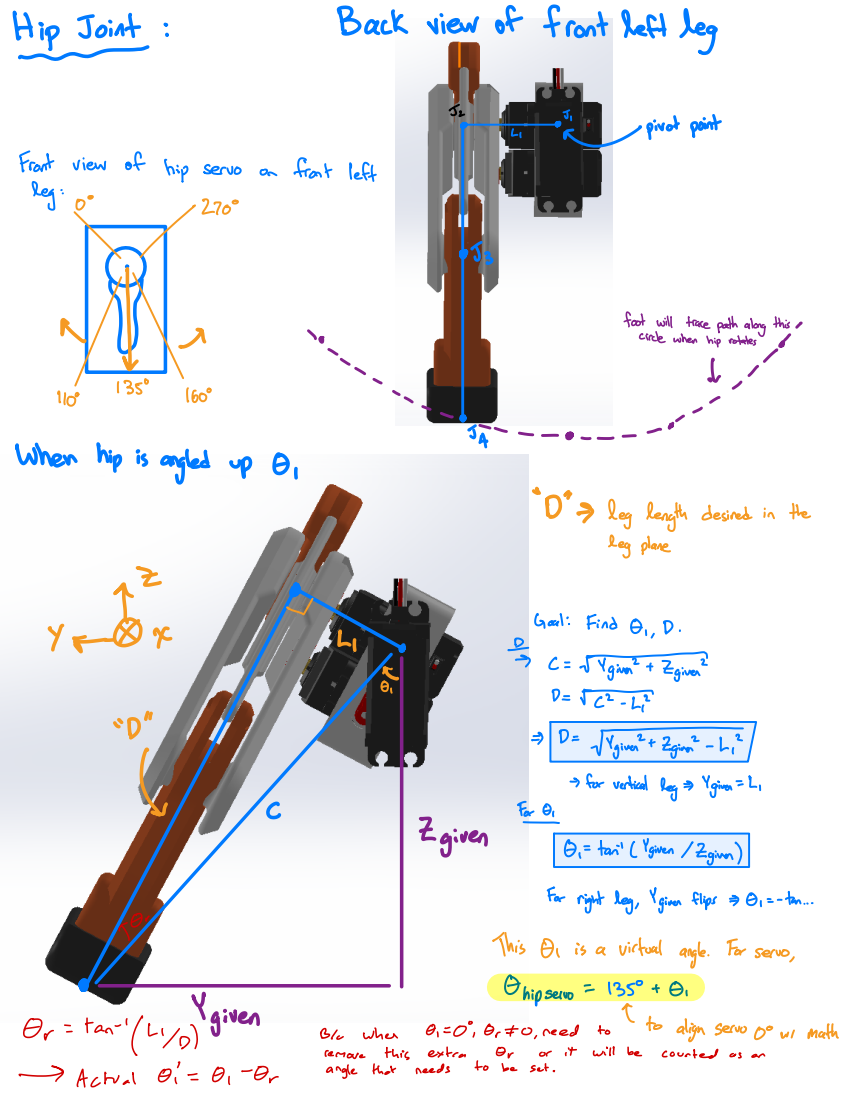
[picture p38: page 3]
Front view; of hip servo; front left; leg :; foot will trace path along thi; circle when; hip rotates; leg plane; Goal :; Find G,; Fina⁺ Zgiven; giner ⁺; Egina" ⁻L,; For E,; Zgiven -; tan" (Ygiven /Zgiven); For right beg,; Ygiven flips => F, = -ta...; This E1 is a; virtual angle.; For servo,; Chipservo =; Ygiven; to align serve pows; math; tant(L/D); when; need; remove; this; extra; will be; counted as; -> Actual 0 =; angle that; needs; sat.

When hip is angled up O,

"D"- leg length desired in the

> for vertical leg = Ygivn = L,

&
Plane (X-E plane) : | Simplify first, | by not accounting for Goffset = 5.88.

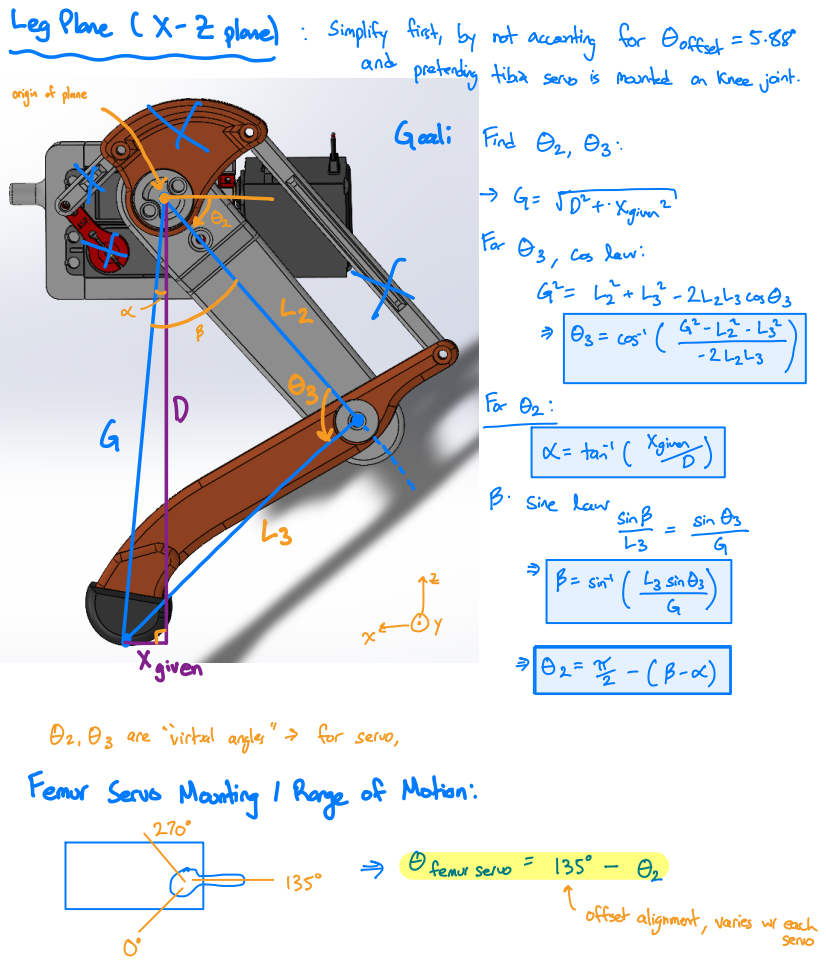
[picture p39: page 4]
Goali Find O2 X; > G =X given; For Os ,; cas law:; 222hscosOs; cos); For O2 :; tai (Xgi); Sinc lawiB i; sint (eit; Xgiven; Oz are "virtual angles" ⁻ for servo,; Ofemvisevo =; offset alignment,; servo

and pretending tibia serve is mounted on knee joint.

origin of plane

Femor Serve Mounting / Range of Motion:

varies ws each

1 =

# parallel pairsE linkages are designed to be 2 consecutive parallelogram

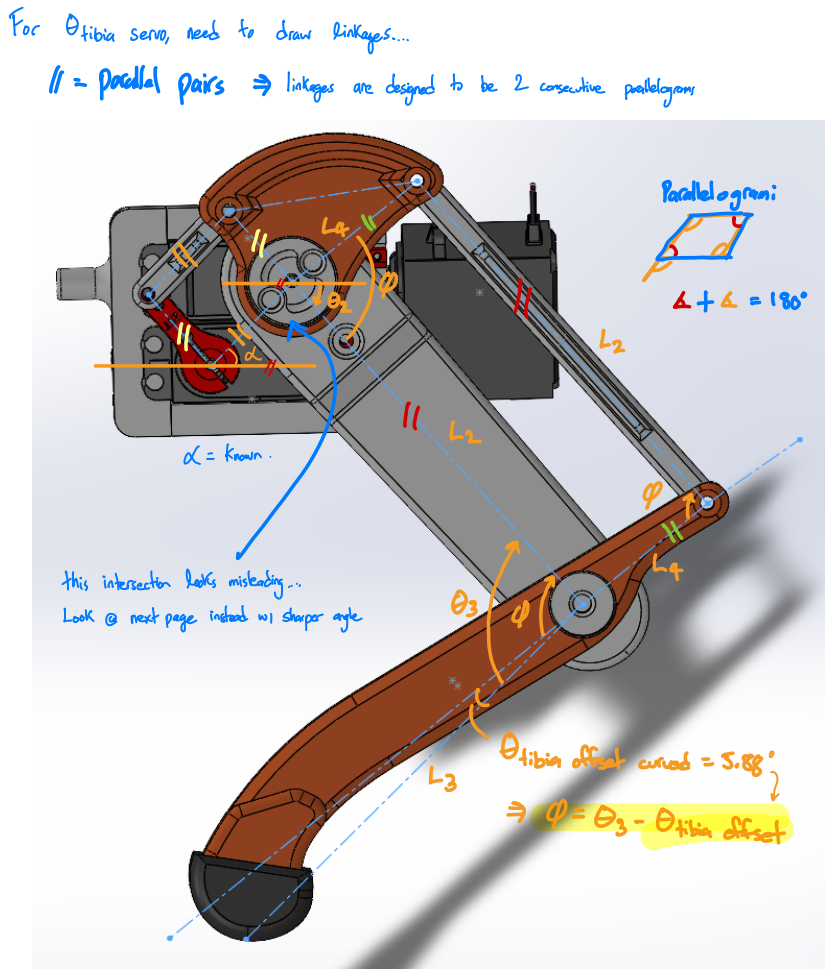
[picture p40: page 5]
For Otibia servo,; need to draw linkages...; Parallelogrami; known; instead we sharper and

this intersection looks misleading....

Looka next page

Etibia offset curved = 5.

Ez-Otibia offset

# Analyzing sharper angle for Oservo tibia

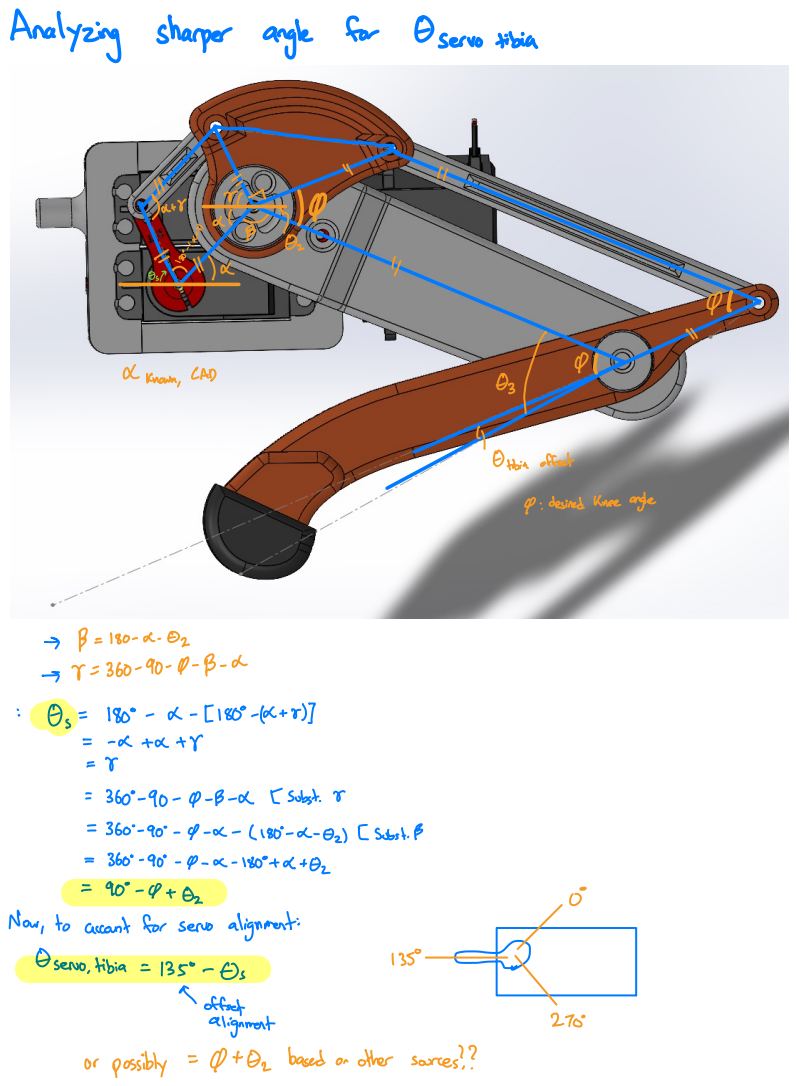
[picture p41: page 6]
& known,; CAD; Otibia offset; 360-90-C-B-x[subst. 2; 2- 82) [Subst.; Now,; to account for servo; alignment:; Eservo,tibia =; ↑ offset; alignment; or possibly =; 0 ⁺O2 based or other sources??

O : desired Knee angle

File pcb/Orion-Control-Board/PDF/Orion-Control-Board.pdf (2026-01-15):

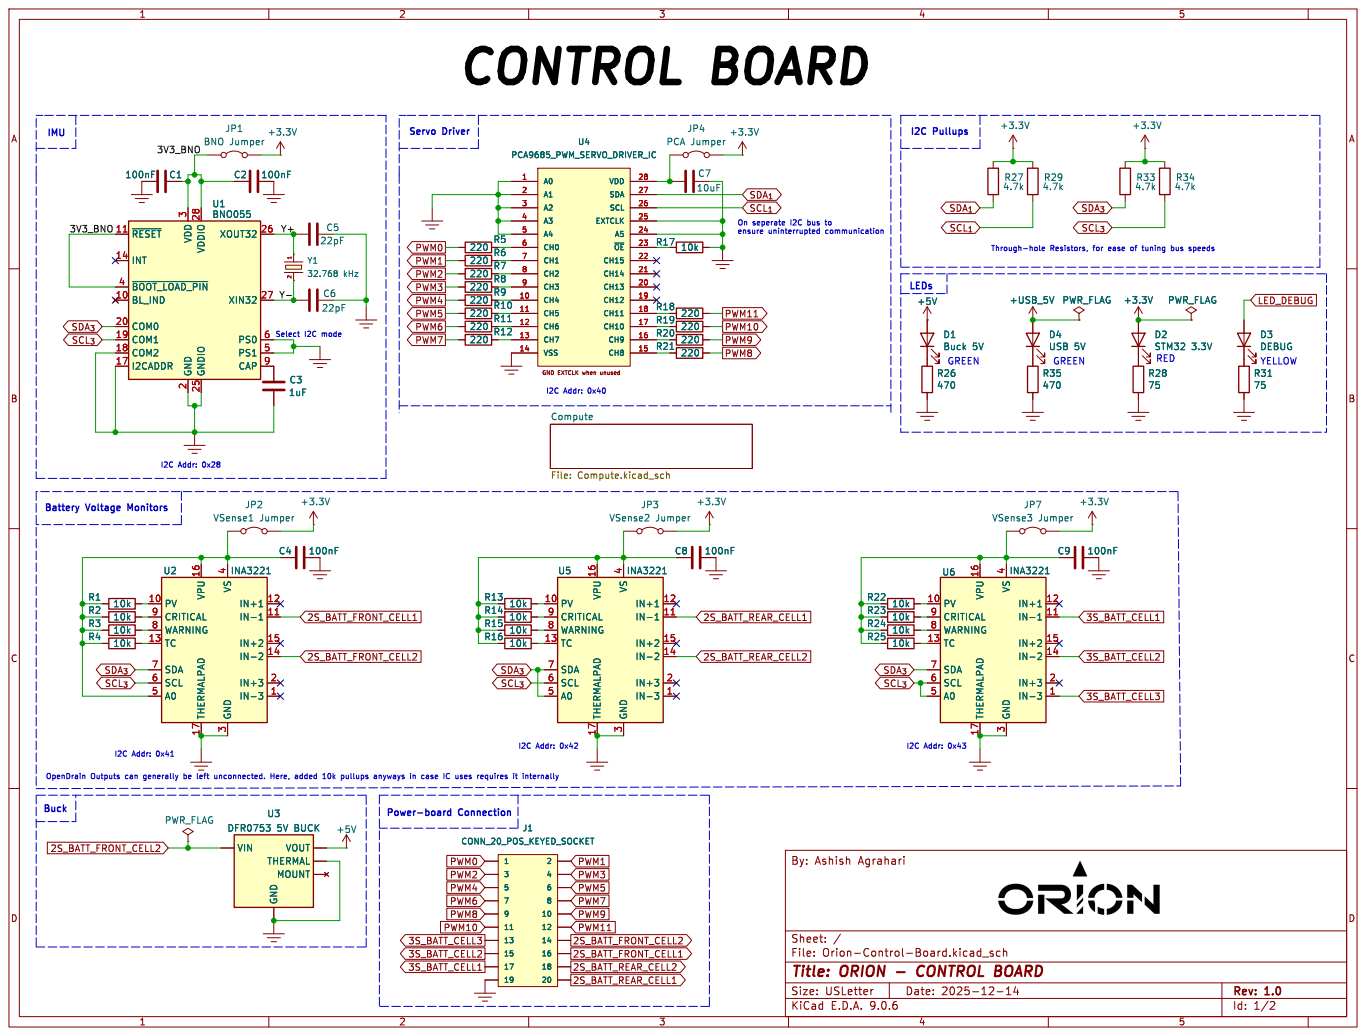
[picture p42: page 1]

2 VDDIO 28 GNDIO 25 XOUT32 26 XIN32 27 PS0 6 PS1 5 CAP 9 U1BNO055 R23 10k D4 USB 5V

Id: 1/2 Title: ORION - CONTROL BOARD

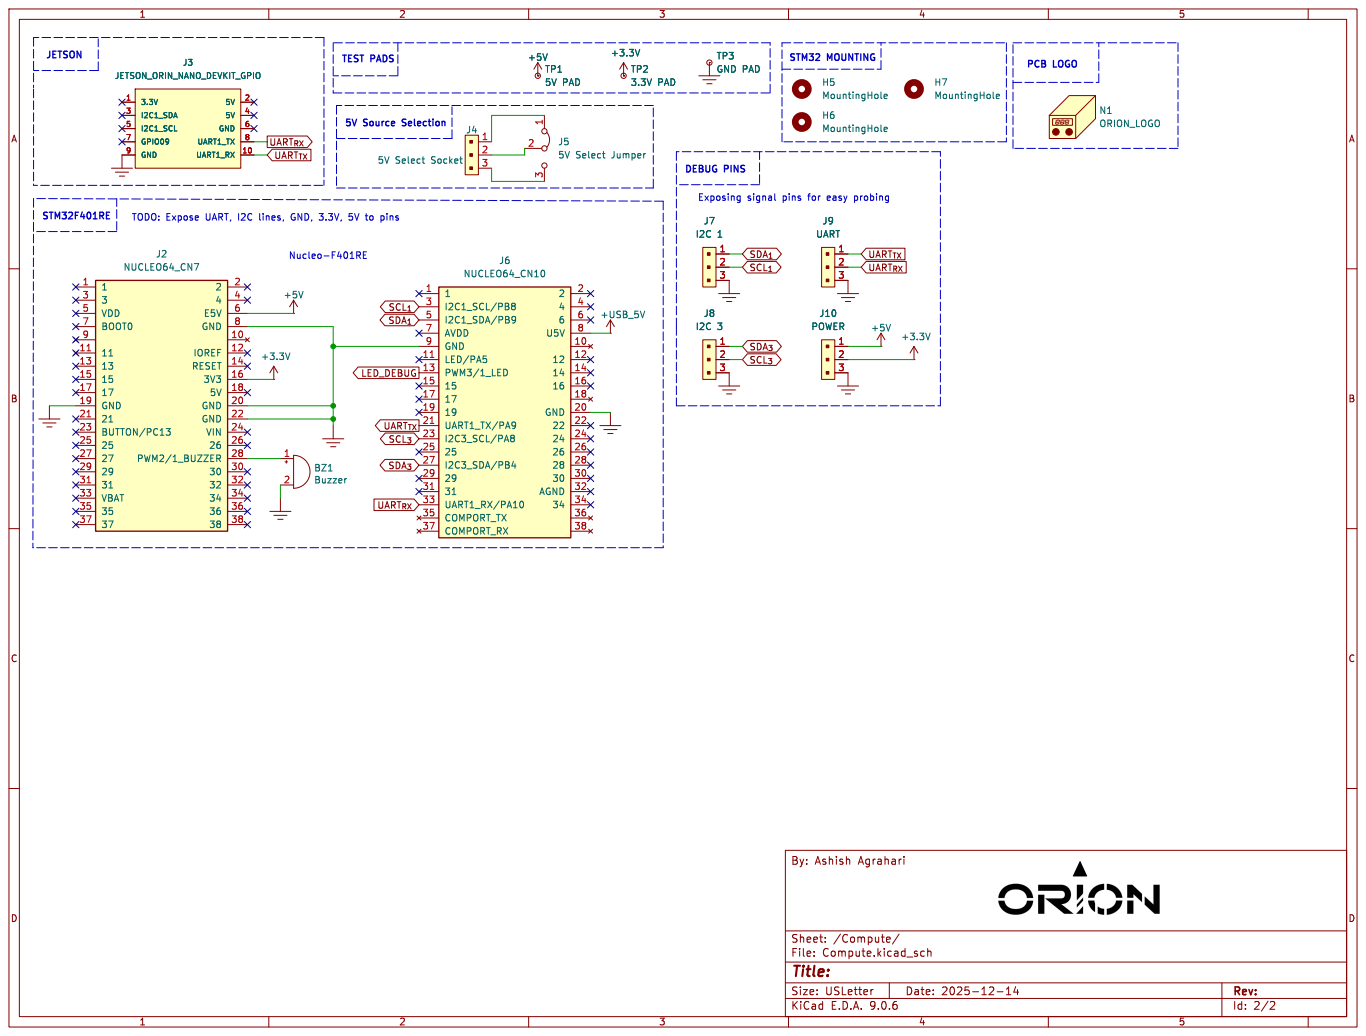
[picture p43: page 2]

Id: 2/2 Title: File: Compute.kicad_sch Sheet: /Compute/

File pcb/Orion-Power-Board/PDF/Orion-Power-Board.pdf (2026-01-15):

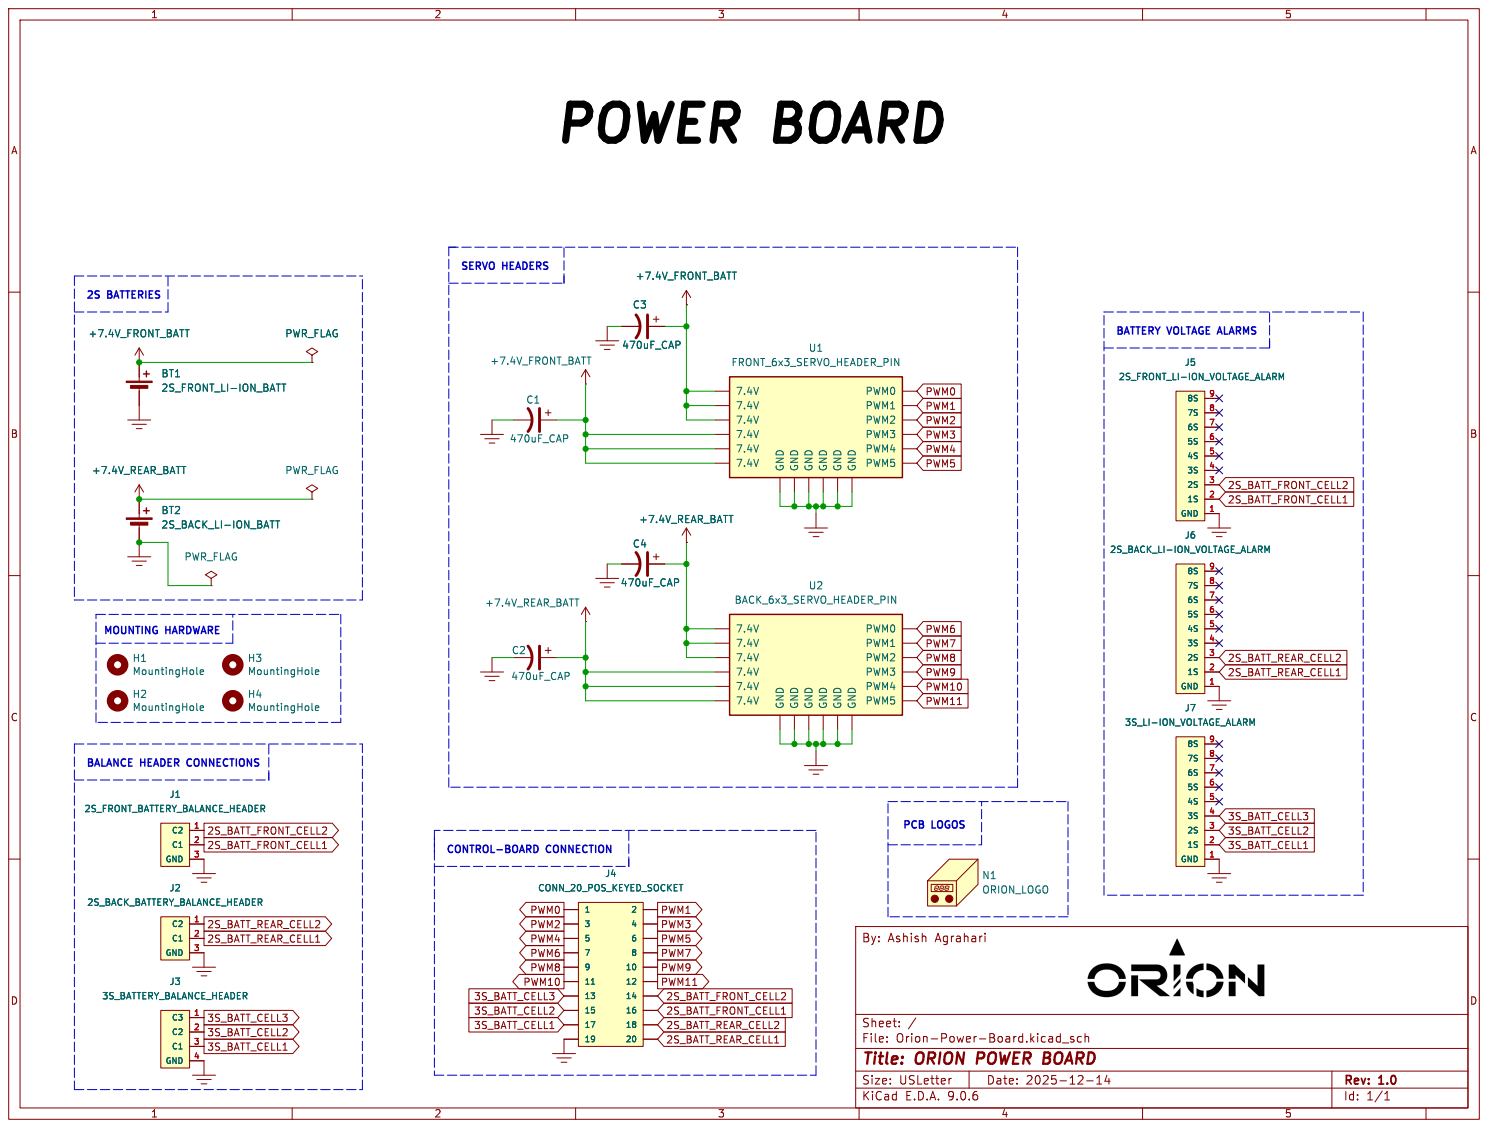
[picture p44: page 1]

PCB LOGOS POWER BOARD

SERVO HEADERS MOUNTING HARDWARE

Id: 1/1 Title: ORION POWER BOARD

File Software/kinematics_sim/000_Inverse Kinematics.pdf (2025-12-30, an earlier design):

# Coordinate System:

Jo | ·

Center of Dog [CoM]; 1: Leg origin M⑧; Femur origin; Tibia origin; foot; R" ([Morigi⁺ [x, y, z) -; [Center of; Rotatitis a; location of foot,; desired rotation matrix; relative to J,; [x y z] = column rector; ② New coord of feet relative to leg's origin :; XYz ,; z]a use; Inverse Kinematics on; this

mentation Control/Rotating Main Body :

① New co-ord of feet relative to Jo ,

center of Robot :

JR ,point to rotate
about.

yaw Rpitch Rroll,

[CoMorigin] + [Center of Rotation =

#verse Kinematics : | known : | Foot (end effector) position

| | Y,

relative to J, Egive3; Desired :; Joint angles :; Ghip; Ofemur Otibia; Intersection of these points; => leg origin J I; Reference Dimensions:; L : Hip; Femur; ↳3: Tibia; varies; "linkage point"; =>: tibia curves,; this point,; the joint, and desired -; foot contact point are not; Collinear; => need to account for offset; fixed; Otibia offset = 5.; angle -; axis alligning joint; and linkage.; desired foot contact point" "; Do I need to get this complex ??

Hi Joint : | Back view of front left leg
5 | pivot point

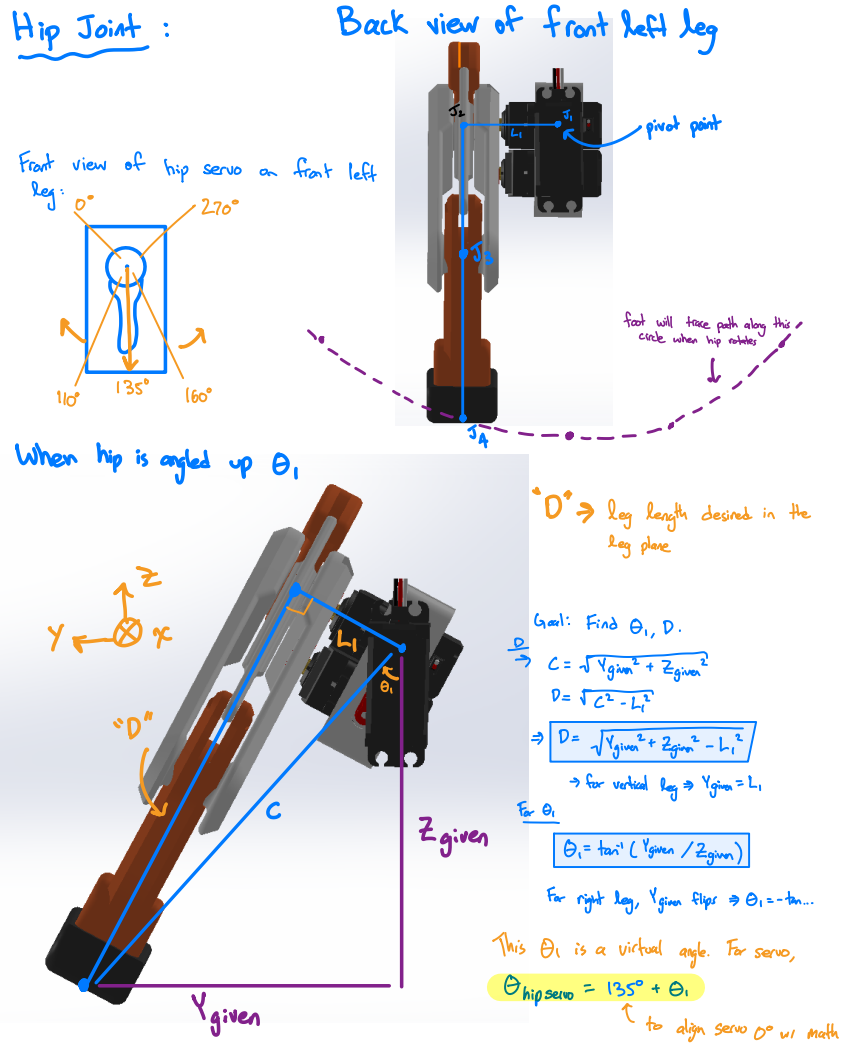
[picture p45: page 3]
Front view; of hip servo; front left; leg :; foot will trace path along thi; circle when; hip rotates; leg plane; Goal :; Find G,; Fina⁺ Zgiven; giner ⁺; Egina" ⁻L,; For E,; Zgiven -; tan" (Ygiven /Zgiven); For right beg,; Ygiven flips => F, = -ta...; This E1 is a; virtual angle.; For servo,; Chipservo =; Ygiven; to align serve pows; math

When hip is angled up O,

"D"- leg length desired in the

> for vertical leg = Ygivn = L,

&
Plane (X-E plane) : | Simplify first, | by not accounting for Goffset = 5.88.

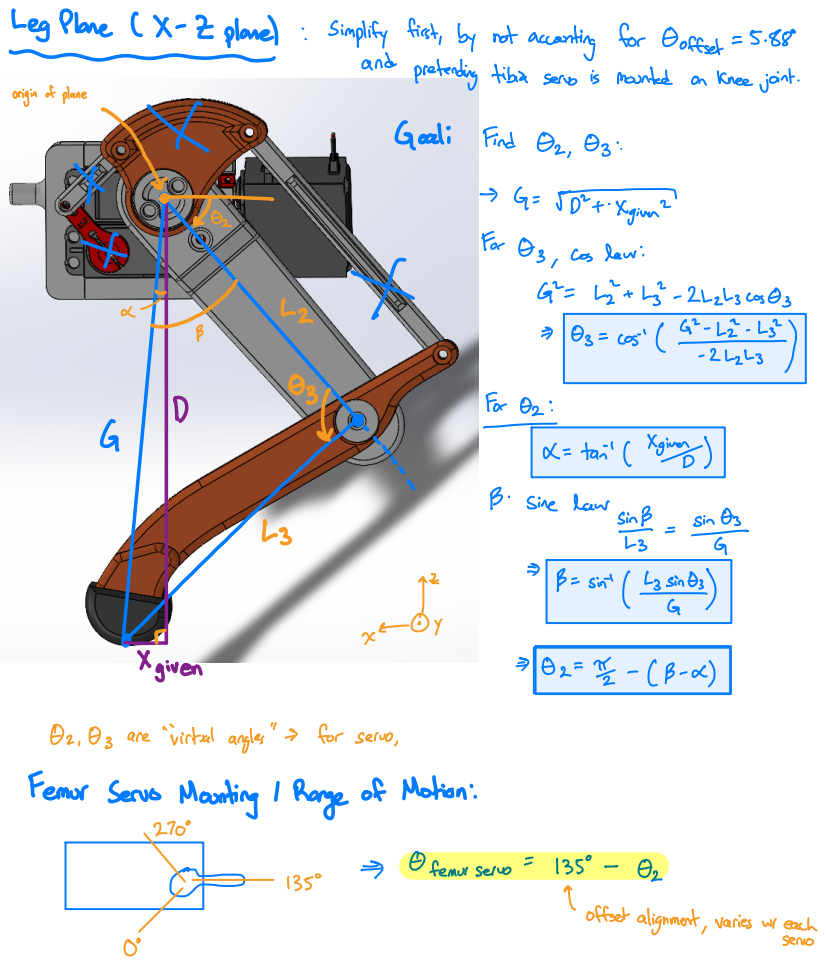
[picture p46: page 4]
Goali Find O2 X; > G =X given; For Os ,; cas law:; 222hscosOs; cos); For O2 :; tai (Xgi); Sinc lawiB i; sint (eit; Xgiven; Oz are "virtual angles" ⁻ for servo,; Ofemvisevo =; offset alignment,; servo

and pretending tibia serve is mounted on knee joint.

origin of plane

Femor Serve Mounting / Range of Motion:

varies ws each

1 =

# parallel pairsE linkages are designed to be 2 consecutive parallelogram

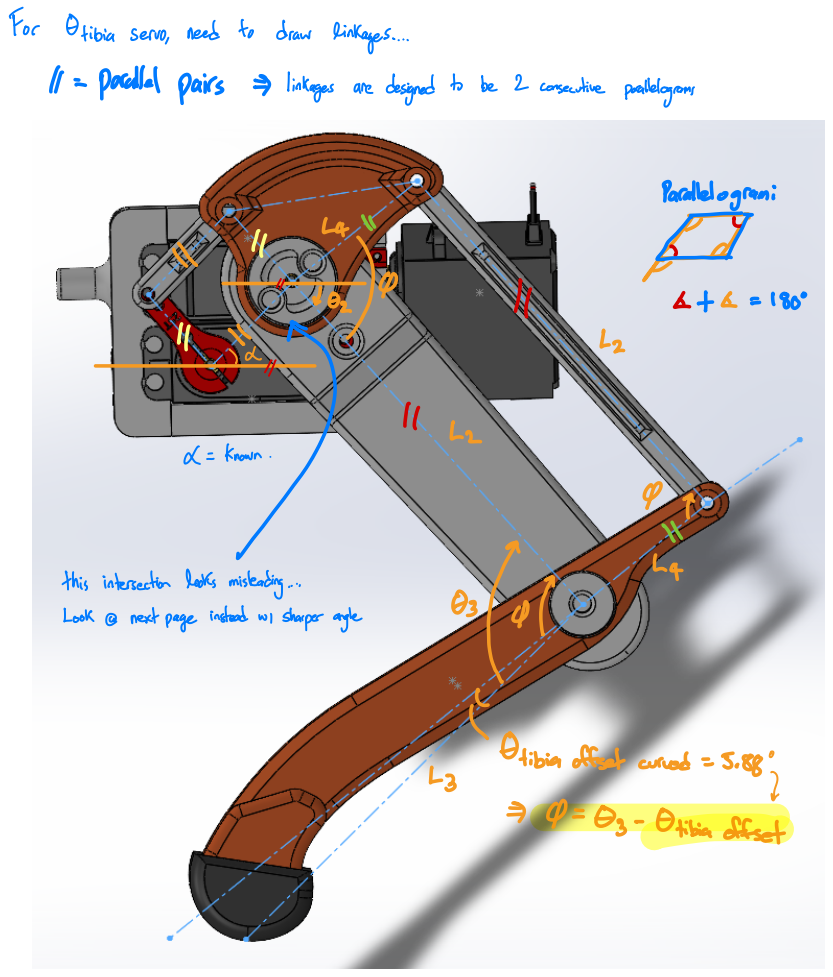
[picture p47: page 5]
For Otibia servo,; need to draw linkages...; Parallelogrami; known; instead we sharper and

this intersection looks misleading....

Looka next page

Etibia offset curved = 5.

Ez-Otibia offset

# Analyzing sharper angle for Oservo tibia

& known,; CAD; Otibia offset; 360-90-C-B-x[subst. 2; 2- 82) [Subst.; Now,; to account for servo; alignment:; Eservo,tibia =; ↑ offset; alignment; or possibly =; 0 ⁺O2 based or other sources??

O : desired Knee angle

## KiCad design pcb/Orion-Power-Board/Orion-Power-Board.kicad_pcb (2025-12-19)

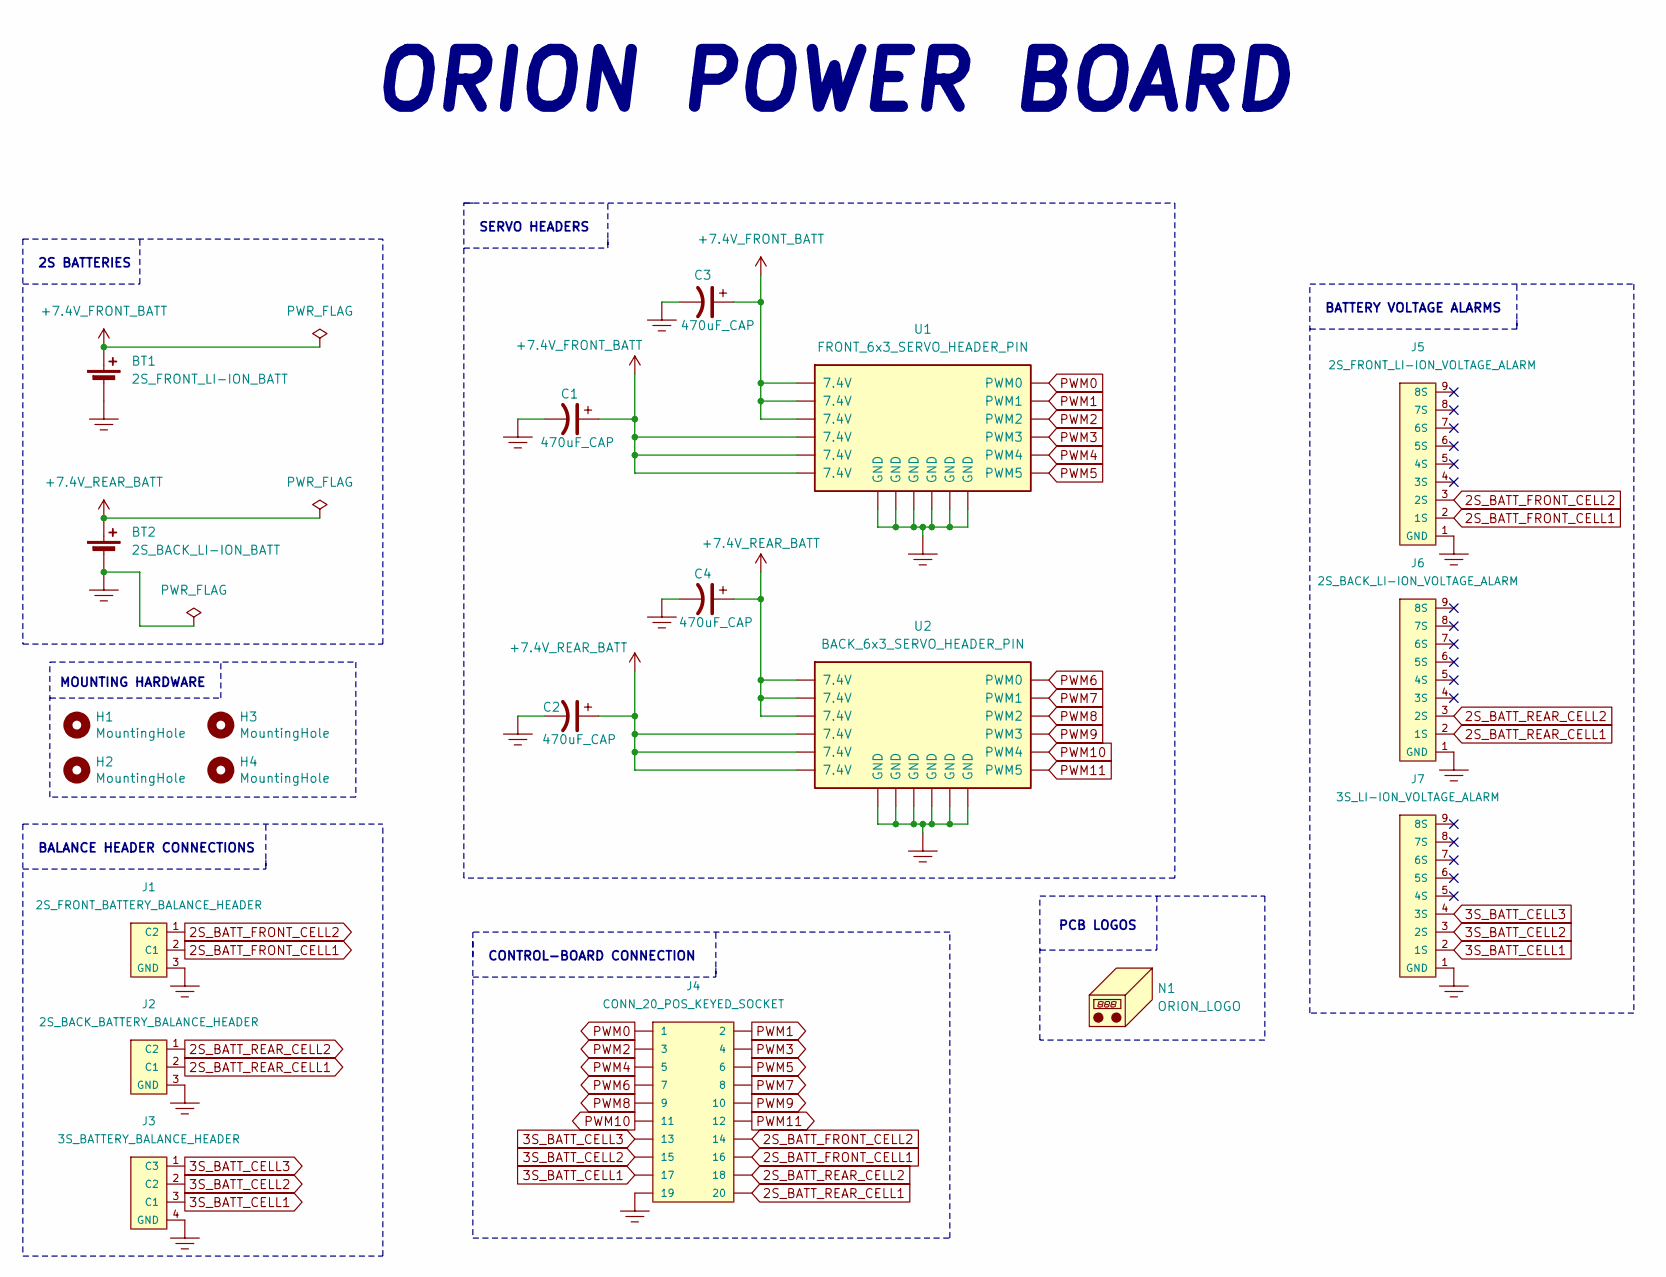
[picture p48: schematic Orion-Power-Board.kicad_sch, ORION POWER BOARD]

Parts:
BT1: 2S_FRONT_LI-ION_BATT; PowerPad_Pair_5.0x5.0mm_2ndPadFlipped
BT2: 2S_BACK_LI-ION_BATT; PowerPad_Pair_5.0x5.0mm_2ndPadFlipped
C1, C2, C3, C4: 470uF_CAP; CP_Radial_D8.0mm_P3.50mm
H1, H2, H3, H4: MountingHole; MountingHole_3.2mm_M3_Pad
J1: 2S_FRONT_BATTERY_BALANCE_HEADER; JST_XH_1x03_P2.54mm_Vertical
J2: 2S_BACK_BATTERY_BALANCE_HEADER; JST_XH_1x03_P2.54mm_Vertical
J3: 3S_BATTERY_BALANCE_HEADER; JST_XH_1x04_P2.54mm_Vertical
J4: CONN_20_POS_KEYED_SOCKET; SULLINS_SBH11-PBPC-D10-ST-BK_SOCKET; Manufacturer Part # SBH11-PBPC-D10-ST-BK; Digikey Part # S9172-ND
J5: 2S_FRONT_LI-ION_VOLTAGE_ALARM; LIPO_VOLTAGE_ALARM
J6: 2S_BACK_LI-ION_VOLTAGE_ALARM; LIPO_VOLTAGE_ALARM
J7: 3S_LI-ION_VOLTAGE_ALARM; LIPO_VOLTAGE_ALARM
N1: ORION_LOGO; Orion-Logo-20mm
U1: FRONT_6x3_SERVO_HEADER_PIN; Servo_PinHeader_3x06_P2.54mm_Vertical
U2: BACK_6x3_SERVO_HEADER_PIN; Servo_PinHeader_3x06_P2.54mm_Vertical

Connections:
2S_BATT_FRONT_CELL1: J1.2 (C1), J4.16, J5.2 (1S)
2S_BATT_FRONT_CELL2: J1.1 (C2), J4.14, J5.3 (2S)
2S_BATT_REAR_CELL1: J2.2 (C1), J4.20, J6.2 (1S)
2S_BATT_REAR_CELL2: J2.1 (C2), J4.18, J6.3 (2S)
3S_BATT_CELL1: J3.3 (C1), J4.17, J7.2 (1S)
3S_BATT_CELL2: J3.2 (C2), J4.15, J7.3 (2S)
3S_BATT_CELL3: J3.1 (C3), J4.13, J7.4 (3S)
+7.4V_FRONT_BATT: BT1.1 (+), C1.1, C3.1, U1.7 (7.4V), U1.8 (7.4V), U1.9 (7.4V), U1.10 (7.4V), U1.11 (7.4V), U1.12 (7.4V)
+7.4V_REAR_BATT: BT2.1 (+), C2.1, C4.1, U2.7 (7.4V), U2.8 (7.4V), U2.9 (7.4V), U2.10 (7.4V), U2.11 (7.4V), U2.12 (7.4V)
GND: BT1.2 (-), BT2.2 (-), C1.2, C2.2, C3.2, C4.2, J1.3 (GND), J2.3 (GND), J3.4 (GND), J4.19, J5.1 (GND), J6.1 (GND), J7.1 (GND), U1.13 (GND), U1.14 (GND), U1.15 (GND), U1.16 (GND), U1.17 (GND), U1.18 (GND), U2.13 (GND), U2.14 (GND), U2.15 (GND), U2.16 (GND), U2.17 (GND), U2.18 (GND)
PWM0: J4.1, U1.1 (PWM0)
PWM1: J4.2, U1.2 (PWM1)
PWM2: J4.3, U1.3 (PWM2)
PWM3: J4.4, U1.4 (PWM3)
PWM4: J4.5, U1.5 (PWM4)
PWM5: J4.6, U1.6 (PWM5)
PWM6: J4.7, U2.1 (PWM0)
PWM7: J4.8, U2.2 (PWM1)
PWM8: J4.9, U2.3 (PWM2)
PWM9: J4.10, U2.4 (PWM3)
PWM10: J4.11, U2.5 (PWM4)
PWM11: J4.12, U2.6 (PWM5)

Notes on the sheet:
BALANCE HEADER CONNECTIONS
SERVO HEADERS
ORION POWER BOARD
MOUNTING HARDWARE
2S BATTERIES
PCB LOGOS
CONTROL-BOARD CONNECTION
BATTERY VOLTAGE ALARMS

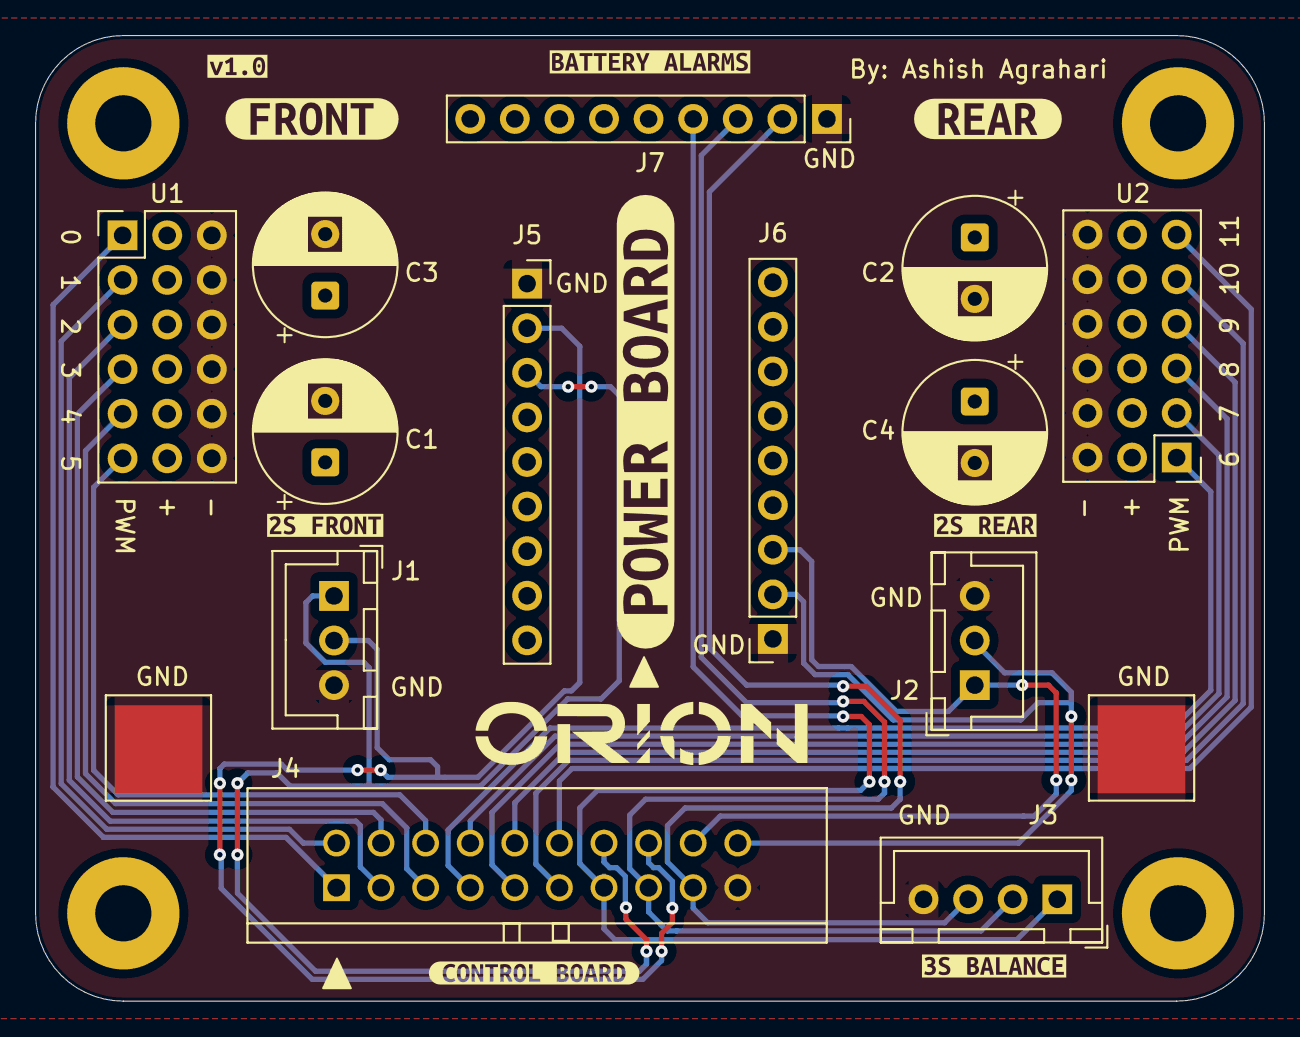
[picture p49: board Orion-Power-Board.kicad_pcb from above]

Board: 2 copper layers, 70.0 x 55.0 mm, 29 parts (0 on the bottom side), 22 nets.

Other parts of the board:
kibuzzard-693F3E2A: G***; kibuzzard-693F3E2A
kibuzzard-693F3F14: G***; kibuzzard-693F3F14
kibuzzard-693F3F70: G***; kibuzzard-693F3F70
kibuzzard-693F65FC: G***; kibuzzard-693F65FC
kibuzzard-693F310D: G***; kibuzzard-693F310D
kibuzzard-693F552C: G***; kibuzzard-693F552C
kibuzzard-693F656E: G***; kibuzzard-693F656E
kibuzzard-693F3101: G***; kibuzzard-693F3101
kibuzzard-693F5536: G***; kibuzzard-693F5536

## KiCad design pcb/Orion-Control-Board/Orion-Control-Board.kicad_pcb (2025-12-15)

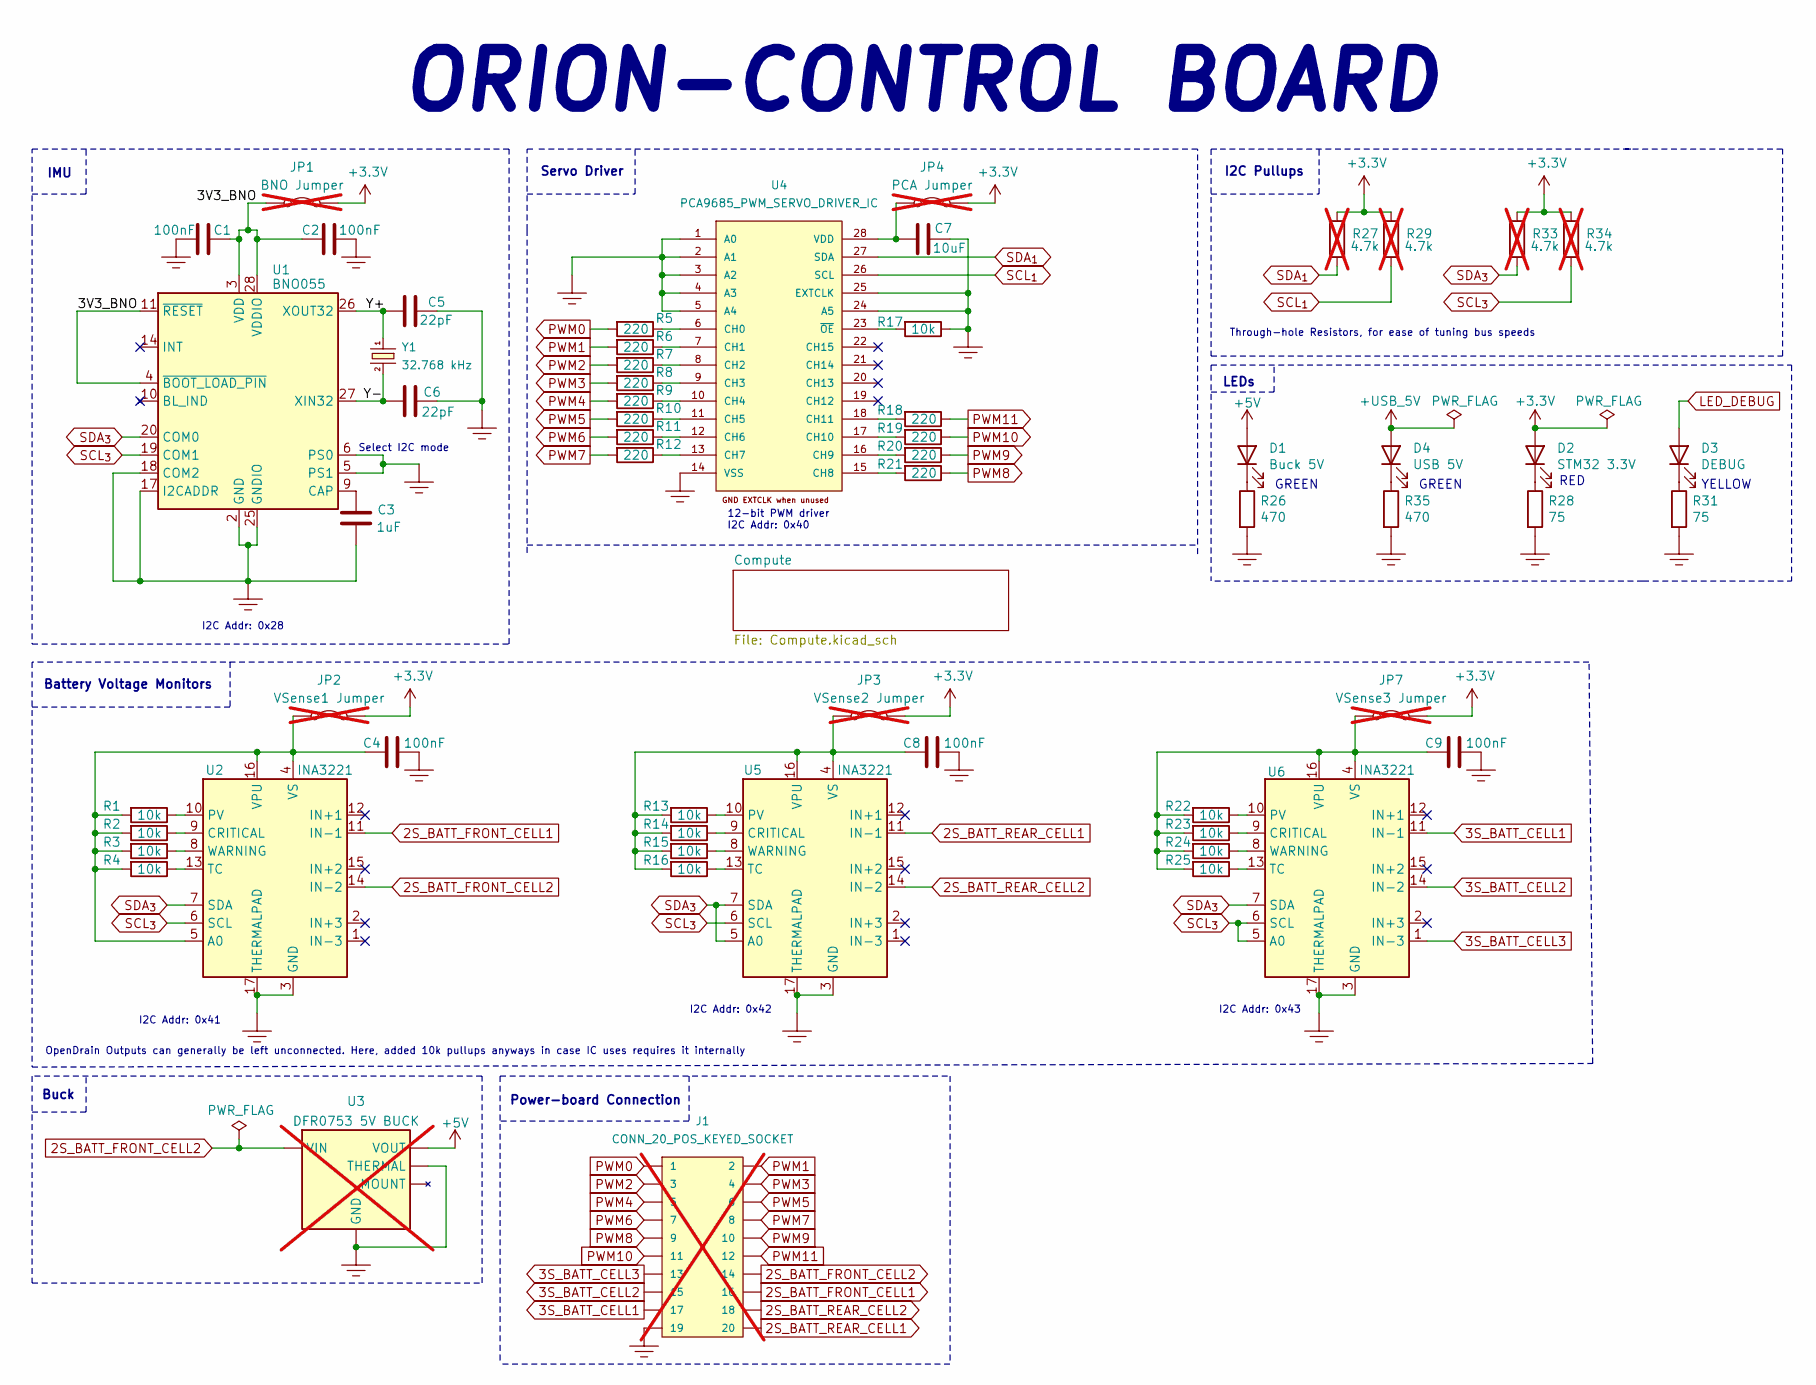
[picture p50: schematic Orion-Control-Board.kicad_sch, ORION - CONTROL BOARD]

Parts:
C1, C2, C4, C8, C9: 100nF; C_0603_1608Metric; JLCPCB Part # C14663
C3: 1uF; C_0603_1608Metric; JLCPCB Part # C15849
C5, C6: 22pF; C_0603_1608Metric; JLCPCB Part # C1653
C7: 10uF; C_0603_1608Metric; JLCPCB Part # C96446
D1: Buck 5V; LED_0805_2012Metric; Manufacturer Part # KT-0805G; JLCPCB Part # C2297
D2: STM32 3.3V; LED_0603_1608Metric; Manufacturer Part # KT-0603R; JLCPCB Part # C2286
D3: DEBUG; LED_0805_2012Metric; Manufacturer Part # KT-0805Y; JLCPCB Part # C2296
D4: USB 5V; LED_0805_2012Metric; Manufacturer Part # KT-0805G; JLCPCB Part # C2297
J1: CONN_20_POS_KEYED_SOCKET; SULLINS_SBH11-PBPC-D10-ST-BK_SOCKET; Manufacturer Part # SBH11-PBPC-D10-ST-BK; Digikey Part # S9172-ND; not fitted
JP1: BNO Jumper; Jumper_PinHeader_1x02_P2.54mm_Vertical_Bridged; not fitted
JP2: VSense1 Jumper; Jumper_PinHeader_1x02_P2.54mm_Vertical_Bridged; not fitted
JP3: VSense2 Jumper; Jumper_PinHeader_1x02_P2.54mm_Vertical_Bridged; not fitted
JP4: PCA Jumper; Jumper_PinHeader_1x02_P2.54mm_Vertical_Bridged; not fitted
JP7: VSense3 Jumper; Jumper_PinHeader_1x02_P2.54mm_Vertical_Bridged; not fitted
R1, R2, R3, R4, R13, R14, R15, R16, R17, R22, R23, R24, R25: 10k; R_0603_1608Metric; JLCPCB Part # C25804
R5, R6, R7, R8, R9, R10, R11, R12, R18, R19, R20, R21: 220; R_0603_1608Metric; JLCPCB Part # C22962
R26, R35: 470; R_0603_1608Metric; JLCPCB Part # C23179
R27, R29, R33, R34: 4.7k; R_SS_Axial_DIN0207_L6.3mm_D2.5mm_P10.16mm_Horizontal; not fitted
R28, R31: 75; R_0603_1608Metric; JLCPCB Part # C4275
U1: BNO055; LGA-28_5.2x3.8mm_P0.5mm; JLCPCB Part # C93216
U2, U5, U6: INA3221; Texas_RGV0016A_VQFN-16-1EP_4x4mm_P0.65mm_EP2.1x2.1mm_Therma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; Manufacturer Part # INA3221AIRGVR; JLCPCB Part # C181255
U3: DFR0753 5V BUCK; DFR0753; Manufacturer Part # DFR0753; Digikey Part # 1738-DFR0753-ND; not fitted
U4: PCA9685_PWM_SERVO_DRIVER_IC; TSSOP-28_4MM; Manufacturer Part # PCA9685PW,118; JLCPCB Part # C2678753
Y1: 32.768 kHz; CRYSTAL-SMD-3.2X1.5MM; JLCPCB Part # C97606

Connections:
2S_BATT_FRONT_CELL1: J1.16, U2.11 (IN-1)
2S_BATT_FRONT_CELL2: J1.14, U2.14 (IN-2), U3.1 (VIN)
2S_BATT_REAR_CELL1: J1.20, U5.11 (IN-1)
2S_BATT_REAR_CELL2: J1.18, U5.14 (IN-2)
3S_BATT_CELL1: J1.17, U6.11 (IN-1)
3S_BATT_CELL2: J1.15, U6.14 (IN-2)
3S_BATT_CELL3: J1.13, U6.1 (IN-3)
+3.3V: D2.2 (A), JP1.2 (B), JP2.2 (B), JP3.2 (B), JP4.2 (B), JP7.2 (B), R27.1, R29.1, R33.1, R34.1; also elsewhere on the board
+5V: D1.2 (A), U3.3 (VOUT); also elsewhere on the board
+USB_5V: D4.2 (A); also elsewhere on the board
/3V3_BNO: C1.2, C2.1, JP1.1 (A), U1.3 (VDD), U1.4 (~BOOT_LOAD_PIN), U1.11 (~RESET), U1.28 (VDDIO)
/Y+: C5.1, U1.26 (XOUT32), Y1.P$1 (1)
/Y-: C6.2, U1.27 (XIN32), Y1.P$2 (2)
GND: C1.1, C2.2, C3.2, C4.2, C5.2, C6.1, C7.1, C8.2, C9.2, J1.19, R17.1, R26.2, R28.2, R31.2, R35.2, U1.2 (GND), U1.5 (PS1), U1.6 (PS0), U1.17 (I2CADDR), U1.18 (COM2), U1.25 (GNDIO), U2.3 (GND), U2.17 (THERMALPAD), U3.2 (GND), U3.4 (THERMAL), U4.1 (A0), U4.2 (A1), U4.3 (A2), U4.4 (A3), U4.5 (A4), U4.14 (VSS), U4.24 (A5), U4.25 (EXTCLK), U5.3 (GND), U5.17 (THERMALPAD), U6.3 (GND), U6.17 (THERMALPAD); also elsewhere on the board
LED_DEBUG: D3.2 (A); also elsewhere on the board
unnamed: D1.1 (K), R26.1
unnamed: D2.1 (K), R28.1
unnamed: D3.1 (K), R31.1
unnamed: D4.1 (K), R35.1
unnamed: C4.1, JP2.1 (A), R1.2, R2.2, R3.2, R4.2, U2.4 (VS), U2.5 (A0), U2.16 (VPU)
unnamed: C8.1, JP3.1 (A), R13.2, R14.2, R15.2, R16.2, U5.4 (VS), U5.16 (VPU)
unnamed: C7.2, JP4.1 (A), U4.28 (VDD)
unnamed: C9.1, JP7.1 (A), R22.2, R23.2, R24.2, R25.2, U6.4 (VS), U6.16 (VPU)
unnamed: C3.1, U1.9 (CAP)
unnamed: R2.1, U2.9 (CRITICAL)
unnamed: R1.1, U2.10 (PV)
unnamed: R4.1, U2.13 (TC)
unnamed: R3.1, U2.8 (WARNING)
unnamed: R5.1, U4.6 (CH0)
unnamed: R6.1, U4.7 (CH1)
unnamed: R7.1, U4.8 (CH2)
unnamed: R8.1, U4.9 (CH3)
unnamed: R9.1, U4.10 (CH4)
unnamed: R10.1, U4.11 (CH5)
unnamed: R11.1, U4.12 (CH6)
unnamed: R12.1, U4.13 (CH7)
unnamed: R21.2, U4.15 (CH8)
unnamed: R20.2, U4.16 (CH9)
unnamed: R19.2, U4.17 (CH10)
unnamed: R18.2, U4.18 (CH11)
unnamed: R17.2, U4.23 (~OE)
unnamed: R14.1, U5.9 (CRITICAL)
unnamed: R13.1, U5.10 (PV)
unnamed: R16.1, U5.13 (TC)
unnamed: R15.1, U5.8 (WARNING)
unnamed: R23.1, U6.9 (CRITICAL)
unnamed: R22.1, U6.10 (PV)
unnamed: R25.1, U6.13 (TC)
unnamed: R24.1, U6.8 (WARNING)
PWM0: J1.1, R5.2
PWM1: J1.2, R6.2
PWM2: J1.3, R7.2
PWM3: J1.4, R8.2
PWM4: J1.5, R9.2
PWM5: J1.6, R10.2
PWM6: J1.7, R11.2
PWM7: J1.8, R12.2
PWM8: J1.9, R21.1
PWM9: J1.10, R20.1
PWM10: J1.11, R19.1
PWM11: J1.12, R18.1
SCL_{1}: R29.2, U4.26 (SCL); also elsewhere on the board
SCL_{3}: R34.2, U1.19 (COM1), U2.6 (SCL), U5.6 (SCL), U6.5 (A0), U6.6 (SCL); also elsewhere on the board
SDA_{1}: R27.2, U4.27 (SDA); also elsewhere on the board
SDA_{3}: R33.2, U1.20 (COM0), U2.7 (SDA), U5.5 (A0), U5.7 (SDA), U6.7 (SDA); also elsewhere on the board

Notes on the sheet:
Through-hole Resistors, for ease of tuning bus speeds
I2C Addr: 0x41
I2C Pullups
Select I2C mode
YELLOW
Battery Voltage Monitors
GREEN
Buck
RED
I2C Addr: 0x43
IMU
I2C Addr: 0x42
Power-board Connection
OpenDrain Outputs can generally be left unconnected. Here, added 10k pullups anyways in case IC uses requires it internally
ORION-CONTROL BOARD
Servo Driver
I2C Addr: 0x28
LEDs
12-bit PWM driver I2C Addr: 0x40

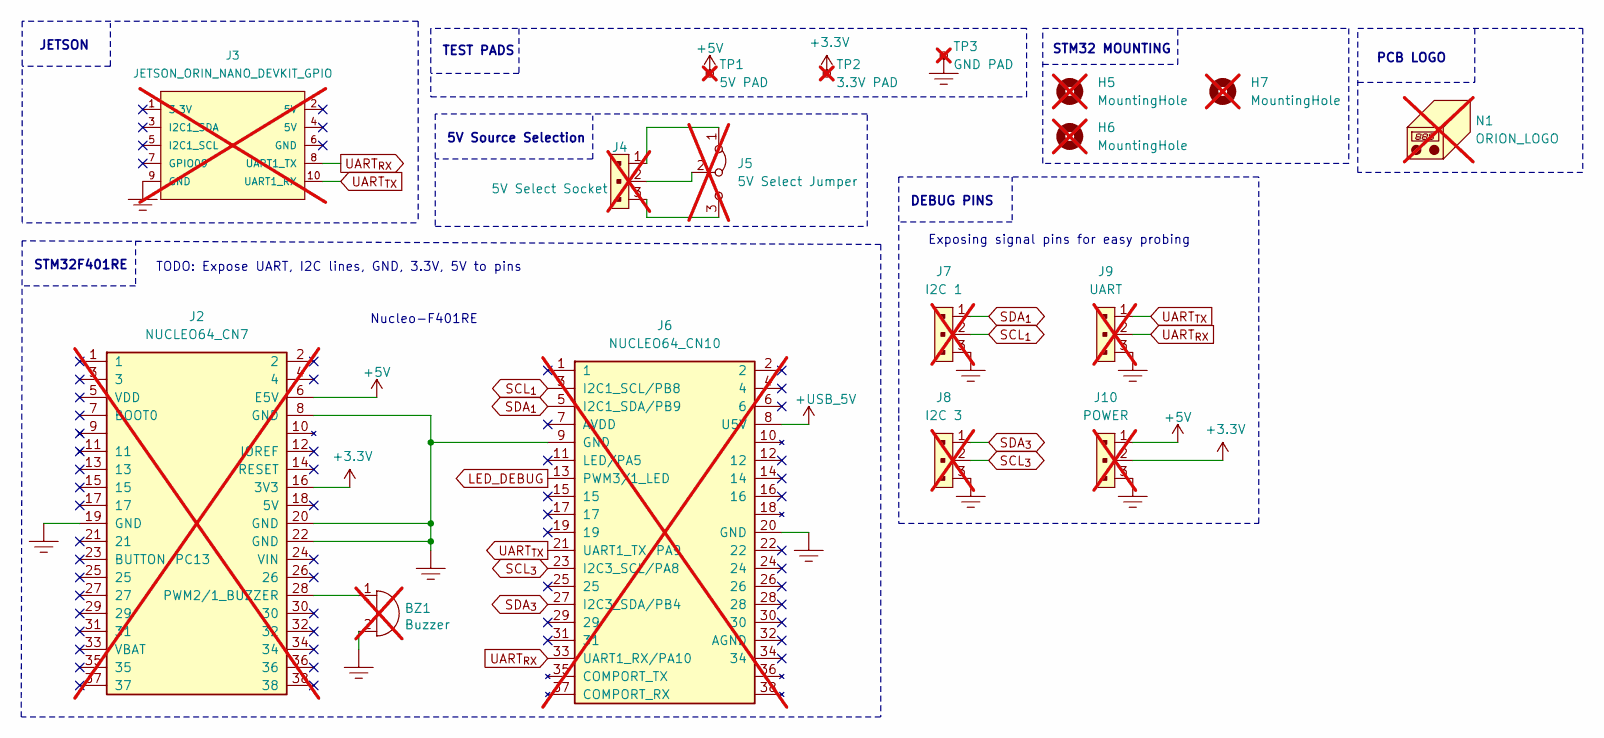
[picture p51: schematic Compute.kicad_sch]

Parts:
BZ1: Buzzer; Buzzer_Generic_D12.2mm_H6.5mm; not fitted
H5, H6, H7: MountingHole; MountingHole_3.2mm_M3; not fitted
J2: NUCLEO64_CN7; PinSocket_2x19_P2.54mm_Vertical; not fitted
J3: JETSON_ORIN_NANO_DEVKIT_GPIO; SULLINS_SBH11-PBPC-D05-ST-BK_SOCKET; Manufacturer Part # SBH11-PBPC-D05-ST-BK; Digikey Part # S9169-ND; not fitted
J4: 5V Select Socket; PinSocket_1x03_P2.54mm_Vertical; MPN 640456-3; Digi-Key_PN A19470-ND; not fitted
J5: 5V Select Jumper; Jumper_PinHeader_1x03_P2.54mm_Vertical_Bridged; not fitted
J6: NUCLEO64_CN10; PinSocket_2x19_P2.54mm_Vertical; not fitted
J7: I2C 1; PinHeader_1x03_P2.54mm_Vertical; MPN 640456-3; Digi-Key_PN A19470-ND; not fitted
J8: I2C 3; PinHeader_1x03_P2.54mm_Vertical; MPN 640456-3; Digi-Key_PN A19470-ND; not fitted
J9: UART; PinHeader_1x03_P2.54mm_Vertical; MPN 640456-3; Digi-Key_PN A19470-ND; not fitted
J10: POWER; PinHeader_1x03_P2.54mm_Vertical; MPN 640456-3; Digi-Key_PN A19470-ND; not fitted
N1: ORION_LOGO; Orion-Logo-20mm; not fitted
TP1: 5V PAD; TestPoint_Pad_5.0x5.0mm; not fitted
TP2: 3.3V PAD; TestPoint_Pad_5.0x5.0mm; not fitted
TP3: GND PAD; TestPoint_Pad_5.0x5.0mm; not fitted

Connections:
+3.3V: J2.16 (3V3), J10.2, TP2.1; also elsewhere on the board
+5V: J2.6 (E5V), J10.1, TP1.1; also elsewhere on the board
+USB_5V: J6.8 (U5V); also elsewhere on the board
GND: BZ1.2 (-), J2.8 (GND), J2.19 (GND), J2.20 (GND), J2.22 (GND), J3.9 (GND), J6.9 (GND), J6.20 (GND), J7.3, J8.3, J9.3, J10.3, TP3.1; also elsewhere on the board
LED_DEBUG: J6.13 (PWM3/1_LED); also elsewhere on the board
unnamed: BZ1.1 (+), J2.28 (PWM2/1_BUZZER)
unnamed: J4.1, J5.1 (A)
unnamed: J4.3, J5.3 (B)
unnamed: J4.2, J5.2 (C)
SCL_{1}: J6.3 (I2C1_SCL/PB8), J7.2; also elsewhere on the board
SCL_{3}: J6.23 (I2C3_SCL/PA8), J8.2; also elsewhere on the board
SDA_{1}: J6.5 (I2C1_SDA/PB9), J7.1; also elsewhere on the board
SDA_{3}: J6.27 (I2C3_SDA/PB4), J8.1; also elsewhere on the board
UART_{RX}: J3.8 (UART1_TX), J6.33 (UART1_RX/PA10), J9.2
UART_{TX}: J3.10 (UART1_RX), J6.21 (UART1_TX/PA9), J9.1

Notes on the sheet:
Nucleo-F401RE
STM32 MOUNTING
STM32F401RE
TEST PADS
JETSON
5V Source Selection
TODO: Expose UART, I2C lines, GND, 3.3V, 5V to pins
DEBUG PINS
PCB LOGO
Exposing signal pins for easy probing

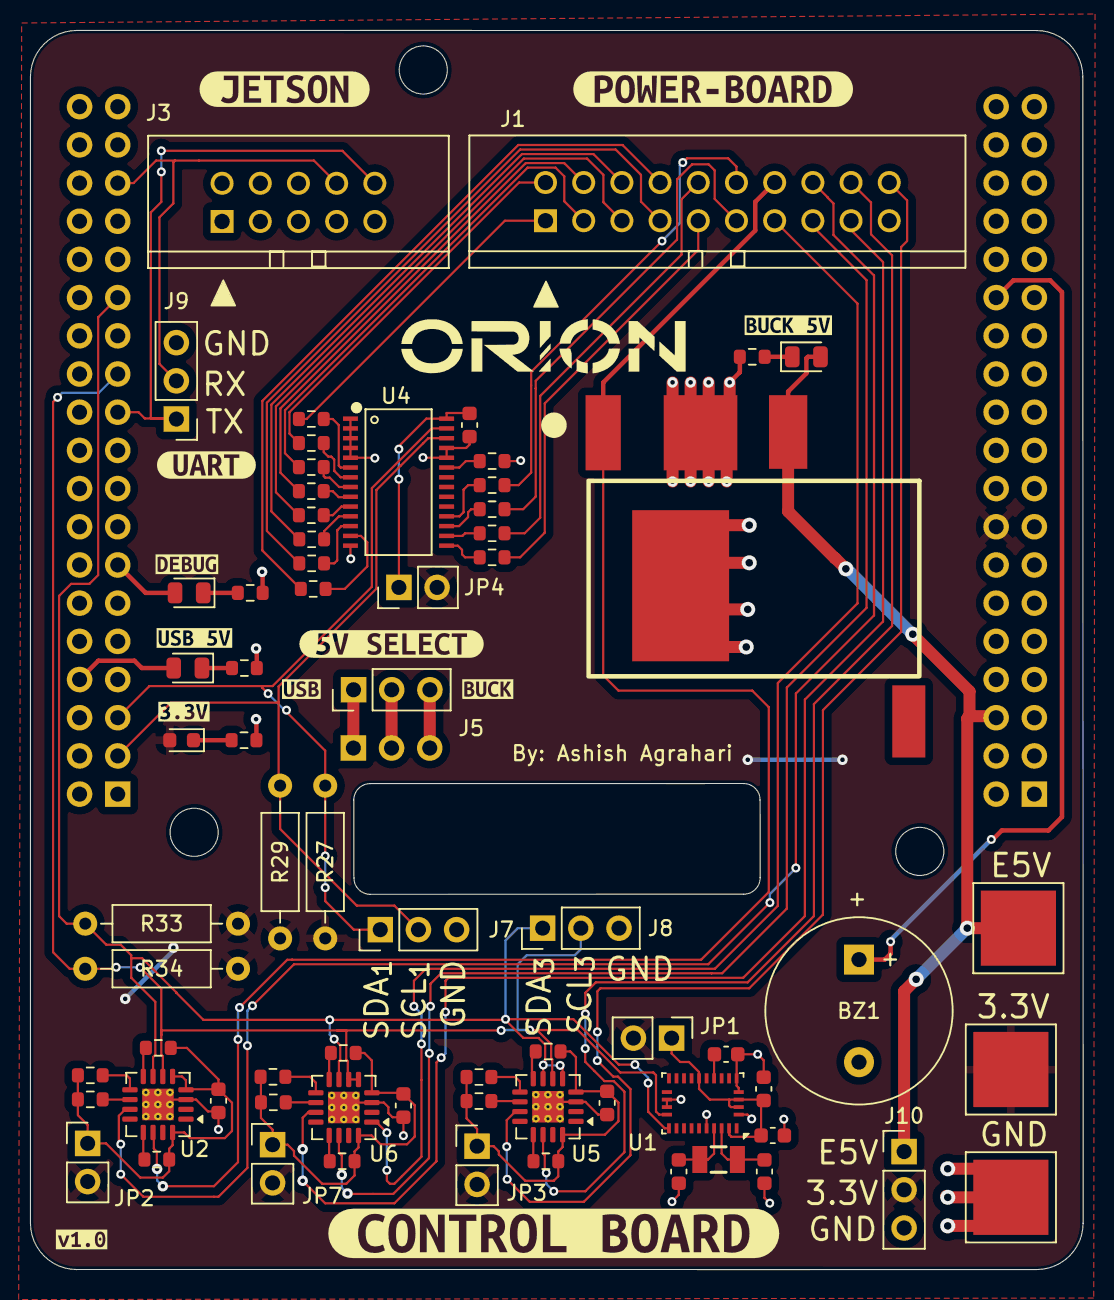
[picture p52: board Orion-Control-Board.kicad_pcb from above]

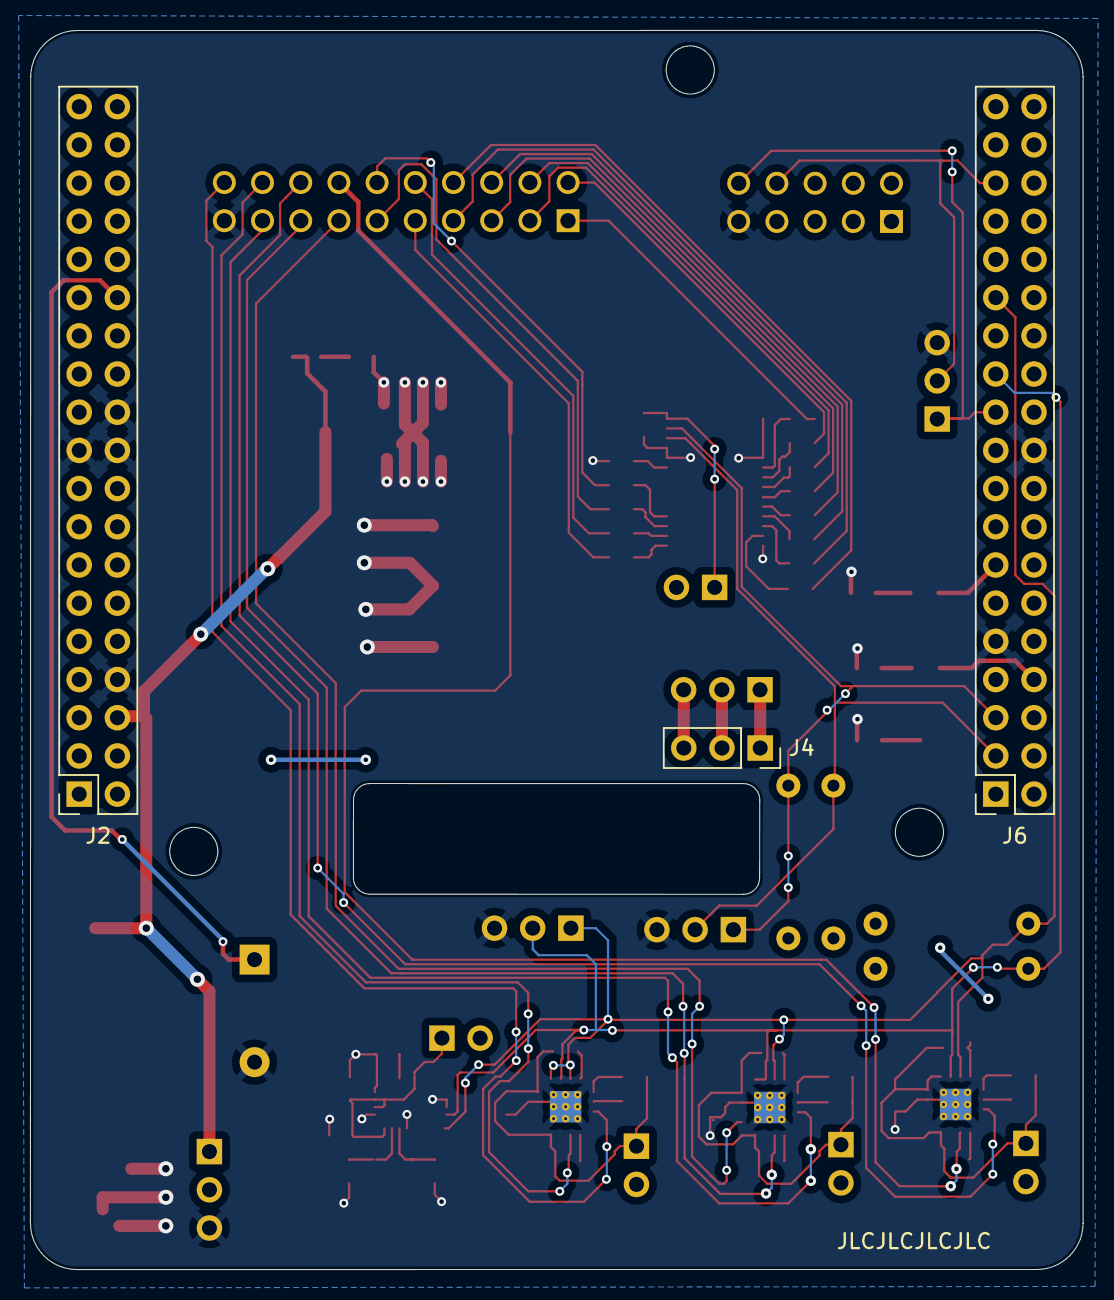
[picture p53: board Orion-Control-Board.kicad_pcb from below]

Board: 2 copper layers, 70.0 x 82.4 mm, 88 parts (3 on the bottom side), 71 nets.

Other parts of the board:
kibuzzard-693EFB3F: G***; kibuzzard-693EFB3F
kibuzzard-693EFB08: G***; kibuzzard-693EFB08
kibuzzard-693EFB23: G***; kibuzzard-693EFB23
kibuzzard-693EFDDB: G***; kibuzzard-693EFDDB
kibuzzard-693EFDEF: G***; kibuzzard-693EFDEF
kibuzzard-693EFDF9: G***; kibuzzard-693EFDF9
kibuzzard-693EFF71: G***; kibuzzard-693EFF71
kibuzzard-693F00A5: G***; kibuzzard-693F00A5
kibuzzard-693F01AF: G***; kibuzzard-693F01AF
kibuzzard-693F01CD: G***; kibuzzard-693F01CD
kibuzzard-693F1F19: G***; kibuzzard-693F1F19
kibuzzard-693F6234: G***; kibuzzard-693F6234

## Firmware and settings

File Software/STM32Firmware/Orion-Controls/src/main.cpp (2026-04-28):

#include <Arduino.h>
#include <Adafruit_PWMServoDriver.h>
#include "LegIK.h"
#include "ServoConfig.h"

Adafruit_PWMServoDriver pwm = Adafruit_PWMServoDriver();

LegIK legFrontLeft(FL_SERVO_CENTER_HIP, FL_SERVO_CENTER_FEMUR, FL_SERVO_CENTER_TIBIA, CH_FL_HIP, CH_FL_FEMUR, CH_FL_TIBIA, true, true);
LegIK legFrontRight(FR_SERVO_CENTER_HIP, FR_SERVO_CENTER_FEMUR, FR_SERVO_CENTER_TIBIA, CH_FR_HIP, CH_FR_FEMUR, CH_FR_TIBIA, true, false);
LegIK legBackLeft(BL_SERVO_CENTER_HIP, BL_SERVO_CENTER_FEMUR, BL_SERVO_CENTER_TIBIA, CH_BL_HIP, CH_BL_FEMUR, CH_BL_TIBIA, false, true);
LegIK legBackRight(BR_SERVO_CENTER_HIP, BR_SERVO_CENTER_FEMUR, BR_SERVO_CENTER_TIBIA, CH_BR_HIP, CH_BR_FEMUR, CH_BR_TIBIA, false, false);

String readString = "";

// Default Home Position
float currentX = 0;
float currentY = 39.3; // L1, mm
float currentZ = 160; // Height of Dog, mm

// Function declarations
void stepGait();
void sineStepGait();
void unisonGait();
void updateLeg(LegIK &leg, float, float, float);
void setServoAngle(int, float);
void standingPose();
void crouchingPose();
void heelingPose();

void setup() {
  delay(5000);
  pwm.begin();
  pwm.setOscillatorFrequency(27000000);
  pwm.setPWMFreq(50); 
  
  // Move all legs to home position
  // updateLeg(legFrontLeft, currentX, currentY, currentZ);
  // updateLeg(legFrontRight, currentX, currentY, currentZ);
  // updateLeg(legBackLeft, currentX, currentY, currentZ);
  // updateLeg(legBackRight, currentX, currentY, currentZ);
  standingPose();
  delay(2000);
  // Serial.begin(9600);
  // Serial.println("Inverse Kinematics Ready. Enter X value:");
}

void loop() {
  
  // Set Z position to commanded input position
  //  while (Serial.available()) {
  //   char c = Serial.read(); 
  //   readString += c;
  //   delay(2);
  // }
  // if (readString.length() > 0) {
  //   float newZ = readString.toFloat();
  //   Serial.print("Moving Z to: "); Serial.println(newZ);
  //   // Update X, keep Y and Z fixed at home position
  //   currentZ = newZ;
  //   updateLeg(currentX, currentY, currentZ);    
  //   readString = "";
  // } 
  
  // Horizontal motion
  // for(int i = -80; i < 80; i+=5){
  //   // Update X, keep Y and Z fixed at home position
  //   updateLeg(i, currentY, currentZ);
  // }
  // for(int i = 80; i > -80; i-=5){
  //   // Update X, keep Y and Z fixed at home position
  //   updateLeg(i, currentY, currentZ);
  // }

  // Veritical Motion
  // for(int i = 60; i < 180; i+=5){
  //   // Update Z, keep Y and X fixed at home position
  //   updateLeg(currentX, currentY, i);
  // }
  // for(int i = 180; i > 60; i-=5){
  //   // Update Z, keep Y and X fixed at home position
  //   updateLeg(currentX, currentY, i);
  // }
  
  // Gait pattern
  // stepGait();
  sineStepGait();
  // standingPose();
  // heelingPose();
  // crouchingPose();
}

void stepGait() {
  const int Z_BASE = 180;     // "Ground" level
  const int STEP_HEIGHT = 50; // Lift height
  const int INTERPOLATION_INCREMENT = 2; // Speed/Resolution
  const int GAIT_X_MAX = 20;
  const int GAIT_X_MIN = -20;
  const float TOTAL_X_DIST = GAIT_X_MAX - GAIT_X_MIN;

  // --- HALF CYCLE 1 ---
  // Pair A (Front Left + Back Right) -> SWING (Move forward + Lift)
  // Pair B (Front Right + Back Left) -> STANCE (Move backward + Ground)
  for (float i = GAIT_X_MIN; i <= GAIT_X_MAX; i += INTERPOLATION_INCREMENT) {
    
    // Calculate SWING Geometry (Sinewave arc)
    float progress = (i - GAIT_X_MIN) / TOTAL_X_DIST; // 0.0 to 1.0
    float angle = progress * PI; 
    int offsetZ = sin(angle) * STEP_HEIGHT;
    int swingZ = Z_BASE - offsetZ;
    float swingX = i; // Moves Min -> Max
    
    // Calculate STANCE Geometry (Linear line)
    // Stance moves opposite to swing (Max -> Min)
    float stanceX = GAIT_X_MAX - (i - GAIT_X_MIN); 
    int stanceZ = Z_BASE;

    // Apply to Diagonal Pairs
    // Pair B: Stance
    updateLeg(legFrontRight, stanceX, currentY, stanceZ);
    updateLeg(legBackLeft, stanceX, currentY, stanceZ);

    // Pair A: Swing
    updateLeg(legFrontLeft, swingX, currentY, swingZ);
    updateLeg(legBackRight, swingX, currentY, swingZ);
  }

  // --- HALF CYCLE 2 ---
  // Pair A (Front Left + Back Right) -> STANCE
  // Pair B (Front Right + Back Left) -> SWING
  for (float i = GAIT_X_MIN; i <= GAIT_X_MAX; i += INTERPOLATION_INCREMENT) {
    
    // Recalculate geometry (same math, just swapped targets)
    float progress = (i - GAIT_X_MIN) / TOTAL_X_DIST;
    float angle = progress * PI;
    int offsetZ = sin(angle) * STEP_HEIGHT;
    int swingZ = Z_BASE - offsetZ;
    float swingX = i;
    
    float stanceX = GAIT_X_MAX - (i - GAIT_X_MIN);
    int stanceZ = Z_BASE;
    
    // Pair B: Swing
    updateLeg(legFrontRight, swingX, currentY, swingZ);
    updateLeg(legBackLeft, swingX, currentY, swingZ);
    // Pair A: Stance
    updateLeg(legFrontLeft, stanceX, currentY, stanceZ);
    updateLeg(legBackRight, stanceX, currentY, stanceZ);

  }
}

void sineStepGait() {
  const int Z_BASE = 180;        // "Ground" level
  const int STEP_HEIGHT = 50;    // Lift height for the swing phase
  const int STANCE_DEPTH = 15;   // Dip depth for the stance phase (pushes down)
  const int INTERPOLATION_INCREMENT = 2; // Speed/Resolution
  const int GAIT_X_MAX = 20;
  const int GAIT_X_MIN = -20;
  const float TOTAL_X_DIST = GAIT_X_MAX - GAIT_X_MIN;

  // --- HALF CYCLE 1 ---
  // Pair A: Front Left + Back Right -> SWING (Move forward + Lift)
  // Pair B: Front Right + Back Left -> STANCE (Move backward + Dip)
  for (float i = GAIT_X_MIN; i <= GAIT_X_MAX; i += INTERPOLATION_INCREMENT) {
    
    float progress = (i - GAIT_X_MIN) / TOTAL_X_DIST; // 0.0 to 1.0
    float angle = progress * PI; 
    
    // Calculate SWING Geometry (Sinewave arc UP)
    int swingZ = Z_BASE - (sin(angle) * STEP_HEIGHT);
    float swingX = i; 
    
    // Calculate STANCE Geometry (Sinewave arc DOWN)
    int stanceZ = Z_BASE + (sin(angle) * STANCE_DEPTH);
    float stanceX = GAIT_X_MAX - (i - GAIT_X_MIN); 

    // Pair B: Stance (Pushing down)
    updateLeg(legFrontRight, stanceX, currentY, stanceZ);
    updateLeg(legBackLeft, stanceX, currentY, stanceZ);

    // Pair A: Swing (Lifting up)
    updateLeg(legFrontLeft, swingX, currentY, swingZ);
    updateLeg(legBackRight, swingX, currentY, swingZ);
  }

  // --- HALF CYCLE 2 ---
  // Pair A: Front Left + Back Right -> STANCE (Move backward + Dip)
  // Pair B: Front Right + Back Left -> SWING (Move forward + Lift)
  for (float i = GAIT_X_MIN; i <= GAIT_X_MAX; i += INTERPOLATION_INCREMENT) {
    
    float progress = (i - GAIT_X_MIN) / TOTAL_X_DIST;
    float angle = progress * PI;
    
    // SWING Geometry
    int swingZ = Z_BASE - (sin(angle) * STEP_HEIGHT);
    float swingX = i;
    
    // STANCE Geometry
    int stanceZ = Z_BASE + (sin(angle) * STANCE_DEPTH);
    float stanceX = GAIT_X_MAX - (i - GAIT_X_MIN);
    
    // Pair B: Swing (Lifting up)
    updateLeg(legFrontRight, swingX, currentY, swingZ);
    updateLeg(legBackLeft, swingX, currentY, swingZ);
    
    // Pair A: Stance (Pushing down)
    updateLeg(legFrontLeft, stanceX, currentY, stanceZ);
    updateLeg(legBackRight, stanceX, currentY, stanceZ);
  }
}

void unisonGait() {
  const int Z_BASE = 180;    // "Ground" level
  const int STEP_HEIGHT = 60; // How high to lift (180 - 60 = 120 units of lift)
  const int INTERPOLATION_INCREMENT = 2;
  const int GAIT_X_MAX = 80;
  const int GAIT_X_MIN = -80;
  
  // SWING PHASE: Move from Back to Front in a semicircle
  for (float i = GAIT_X_MIN; i < GAIT_X_MAX; i += INTERPOLATION_INCREMENT) {
    // Map the X position to a 0-180 degree range for the Sine wave
    float angle = ( (i - GAIT_X_MIN) / (GAIT_X_MAX - GAIT_X_MIN) ) * PI;
    
    // Calculate Z: Start at base and subtract the sine offset
    int offsetZ = sin(angle) * STEP_HEIGHT;
    int currentZ = Z_BASE - offsetZ;
    updateLeg(legFrontLeft, i, currentY, currentZ);
    updateLeg(legFrontRight, i, currentY, currentZ);
    updateLeg(legBackLeft, i, currentY, currentZ);
    updateLeg(legBackRight, i, currentY, currentZ);
  }

  // STANCE PHASE: Move from Front to Back horizontally
  // This is the part where the robot actually pushes its body forward
  for (int i = GAIT_X_MAX; i > GAIT_X_MIN; i -= INTERPOLATION_INCREMENT) {
    updateLeg(legFrontLeft, i, currentY, Z_BASE); 
    updateLeg(legFrontRight, i, currentY, Z_BASE);
    updateLeg(legBackLeft, i, currentY, Z_BASE);
    updateLeg(legBackRight, i, currentY, Z_BASE);
  }
}

void standingPose() {
    int back_x = 0;
    int front_x = 0;
    int back_z = 160;
    int front_z = 160;
    int y = 0; // y is not used

    updateLeg(legFrontLeft, front_x, y, front_z);
    updateLeg(legFrontRight, front_x, y, front_z);
    updateLeg(legBackLeft, back_x, y, back_z);
    updateLeg(legBackRight, back_x, y, back_z);
}

void crouchingPose() {
    int back_x = 0;
    int front_x = 0;
    int back_z = 100;
    int front_z = 100;
    int y = 0; // y is not used

    updateLeg(legFrontLeft, front_x, y, front_z);
    updateLeg(legFrontRight, front_x, y, front_z);
    updateLeg(legBackLeft, back_x, y, back_z);
    updateLeg(legBackRight, back_x, y, back_z);
}

void heelingPose() {
    int back_x = -20;
    int front_x = -20;
    int back_z = 120;
    int front_z = 180;
    int y = 0; // y is not used

    updateLeg(legFrontLeft, front_x, y, front_z);
    updateLeg(legFrontRight, front_x, y, front_z);
    updateLeg(legBackLeft, back_x, y, back_z);
    updateLeg(legBackRight, back_x, y, back_z);
}

void updateLeg(LegIK &leg, float x, float y, float z) {
  if (leg.calculate(x, y, z)) {
    float h = leg.getHipServoAngle();
    float f = leg.getFemurServoAngle();
    float t = leg.getTibiaServoAngle();
    setServoAngle(leg.getHipServoChannel(), h);
    setServoAngle(leg.getFemurServoChannel(), f);
    setServoAngle(leg.getTibiaServoChannel(), t);

    // Debug output
    // Serial.print(" Hip: "); Serial.print(h);
    // Serial.print(" Femur: "); Serial.print(f);
    // Serial.print(" Tibia: "); Serial.println(t);
    // delay(1);
  } else {
    Serial.println("Error: Target out of reach.");
  }
}

void setServoAngle(int channel, float angle) {
  // Constraint for safety
  if (angle < 0) angle = 0;
  if (angle > 270) angle = 270;
  
  // Allow 2 decimal places in servo angle
  int pulse = map(angle * 100, 0, 27000, SERVO_MIN, SERVO_MAX);
  pwm.writeMicroseconds(channel, pulse);
}

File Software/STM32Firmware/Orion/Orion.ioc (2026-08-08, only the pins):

Mcu.UserName=STM32F401RETx
PA0-WKUP.GPIO_Label=PWM2/1_Buzzer
PA0-WKUP.Signal=S_TIM2_CH1_ETR
PA10.Signal=USART1_RX
PA13.GPIO_Label=TMS
PA13.Signal=SYS_JTMS-SWDIO
PA14.GPIO_Label=TCK
PA14.Signal=SYS_JTCK-SWCLK
PA2.GPIO_Label=USART_TX
PA2.Signal=USART2_TX
PA3.GPIO_Label=USART_RX
PA3.Signal=USART2_RX
PA5.GPIO_Label=LD2 [Green Led]
PA5.Signal=GPIO_Output
PA6.GPIO_Label=LED_DEBUG
PA6.Signal=GPIO_Output
PA8.Signal=I2C3_SCL
PA9.Signal=USART1_TX
PB3.GPIO_Label=SWO
PB3.Signal=SYS_JTDO-SWO
PB4.Signal=I2C3_SDA
PB8.Signal=I2C1_SCL
PB9.Signal=I2C1_SDA
PC13-ANTI_TAMP.GPIO_Label=B1 [Blue PushButton]
PC13-ANTI_TAMP.Signal=GPXTI13
PC14-OSC32_IN.Signal=RCC_OSC32_IN
PC15-OSC32_OUT.Signal=RCC_OSC32_OUT

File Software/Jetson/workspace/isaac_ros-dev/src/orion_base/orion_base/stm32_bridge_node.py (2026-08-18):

import math
import rclpy
from rclpy.node import Node
from orion_msgs.msg import OrionMotionCmd, OrionImuFeedback, OrionBatteryVoltage, OrionLegInfo
from std_msgs.msg import Float32MultiArray
from sensor_msgs.msg import JointState
import serial
import struct
from typing import Tuple

TELEM_PKT_SIZE = 99 # 2 header + 96 payload (12 imu bytes, 36 battery voltage bytes, 48 joint angle bytes) + 1 checksum

class STM32Bridge(Node):
    def __init__(self):
        super().__init__('stm32_bridge_node')
        self.motion_subscriber = self.create_subscription(OrionMotionCmd, 'orion_motion_cmd', self.motion_callback, 10)

        # Configure Serial Port (UART)
        self.declare_parameter('serial_port', '/dev/ttyTHS1')
        self.declare_parameter('baud_rate', 460800)
        self.declare_parameter('send_rate_hz', 50.0)
        serial_port = self.get_parameter('serial_port').value
        baud_rate = self.get_parameter('baud_rate').value
        send_rate = 1.0 / self.get_parameter('send_rate_hz').value
        
        try:
            self.serial_conn = serial.Serial(serial_port, baud_rate, timeout=0.1)
            self.get_logger().info(f"Successfully opened {serial_port} at {baud_rate} baud.")
        except serial.SerialException as e:
            self.get_logger().error(f"Failed to open serial port: {e}")
            self.serial_conn = None

        self.latest_msg = OrionMotionCmd()
        self.latest_msg.cmd_type = OrionMotionCmd.CMD_NORMAL

        # Create a timer to write to UART
        self.write_timer = self.create_timer(send_rate, self.send_to_stm32)

        # Battery Telemetry Publisher
        self.battery_front_pub = self.create_publisher(OrionBatteryVoltage, 'battery_voltage_front', 10)
        self.battery_rear_pub = self.create_publisher(OrionBatteryVoltage, 'battery_voltage_rear', 10)
        self.battery_jetson_pub = self.create_publisher(OrionBatteryVoltage, 'battery_voltage_jetson', 10)

        # IMU publisher
        self.imu_pub = self.create_publisher(OrionImuFeedback, 'imu_degrees', 10)

        # Custom Joint angle publishers
        self.front_left_leg_pub = self.create_publisher(OrionLegInfo, 'joint_angles_front_left', 10)
        self.front_right_leg_pub = self.create_publisher(OrionLegInfo, 'joint_angles_front_right', 10)
        self.back_left_leg_pub = self.create_publisher(OrionLegInfo, 'joint_angles_back_left', 10)
        self.back_right_leg_pub = self.create_publisher(OrionLegInfo, 'joint_angles_back_right', 10)

        # Standard JointState publisher
        self.joint_state_pub = self.create_publisher(JointState, 'joint_states', 10)

        # Read timer and buffer
        self.rx_buffer = bytearray()
        self.read_timer = self.create_timer(0.02, self.read_from_stm32) # 50 Hz read check

    def calculate_checksum(self, payload_bytes):
        # Simple XOR checksum of the payload
        checksum = 0
        for byte in payload_bytes:
            checksum ^= byte
        return checksum

    def motion_callback(self, msg):
        # Store the latest command
        self.latest_msg = msg

    def read_from_stm32(self):
        if not self.serial_conn or not self.serial_conn.is_open:
            self.get_logger().error("No connection!")
            return

        # Read everything available in the serial buffer
        if self.serial_conn.in_waiting > 0:
            new_bytes = self.serial_conn.read(self.serial_conn.in_waiting)
            self.rx_buffer.extend(new_bytes)

        # Process packets in the buffer
        while len(self.rx_buffer) >= TELEM_PKT_SIZE:
            # Look for Header: 0xAA and 0x55 (this particular order means recieving from STM to jetson)
            if self.rx_buffer[0] == 0xAA and self.rx_buffer[1] == 0x55:
                packet = self.rx_buffer[:TELEM_PKT_SIZE]
                
                # Validate Checksum (XOR from index 2 to 37)
                cksum = 0
                for b in packet[2:TELEM_PKT_SIZE-1]:
                    cksum ^= b
                
                if cksum == packet[TELEM_PKT_SIZE-1]:
                    # Unpack 24 little-endian floats (96 bytes)
                    floats = struct.unpack('<24f', bytes(packet[2:TELEM_PKT_SIZE-1]))
                    
                    # Split data
                    imu_data = floats[:3]
                    battery_data = floats[3:12]
                    joint_data = floats[12:]

                    # Publish imu data
                    imu_msg = OrionImuFeedback()
                    imu_msg.roll = imu_data[0]
                    imu_msg.pitch = imu_data[1]
                    imu_msg.yaw = imu_data[2]
                    self.imu_pub.publish(imu_msg)

                    # Publish battery data
                    battery_front_msg = OrionBatteryVoltage()
                    battery_front_msg.cell_1 = battery_data[0]
                    battery_front_msg.cell_2 = battery_data[1]-battery_data[0]
                    battery_front_msg.total = battery_data[1]
                    self.battery_front_pub.publish(battery_front_msg)

                    battery_rear_msg = OrionBatteryVoltage()
                    battery_rear_msg.cell_1 = battery_data[3]
                    battery_rear_msg.cell_2 = battery_data[4]-battery_data[3]
                    battery_rear_msg.total = battery_data[4]
                    self.battery_rear_pub.publish(battery_rear_msg)

                    battery_jetson_msg = OrionBatteryVoltage()
                    battery_jetson_msg.cell_1 = battery_data[6]
                    battery_jetson_msg.cell_2 = battery_data[7]-battery_data[6]
                    battery_jetson_msg.cell_3 = battery_data[8]-battery_data[7]
                    battery_jetson_msg.total = battery_data[8]
                    self.battery_jetson_pub.publish(battery_jetson_msg)

                    # Publish custom joint angle data (Kept in degrees)
                    front_left_msg = OrionLegInfo()
                    front_left_msg.hip_angle = joint_data[0]
                    front_left_msg.femur_angle = joint_data[1]
                    front_left_msg.tibia_angle = joint_data[2]
                    self.front_left_leg_pub.publish(front_left_msg)

                    front_right_msg = OrionLegInfo()
                    front_right_msg.hip_angle = joint_data[3]
                    front_right_msg.femur_angle = joint_data[4]
                    front_right_msg.tibia_angle = joint_data[5]
                    self.front_right_leg_pub.publish(front_right_msg)

                    back_left_msg = OrionLegInfo()
                    back_left_msg.hip_angle = joint_data[6]
                    back_left_msg.femur_angle = joint_data[7]
                    back_left_msg.tibia_angle = joint_data[8]
                    self.back_left_leg_pub.publish(back_left_msg)
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

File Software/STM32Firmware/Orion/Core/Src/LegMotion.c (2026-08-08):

#include "LegMotion.h"

/* Global Leg Objects */
LegIK_t legFrontLeft;
LegIK_t legFrontRight;
LegIK_t legBackLeft;
LegIK_t legBackRight;

float currentX = 0;
float currentY = 39.3f; // L1, mm
float currentZ = 160.0f; // Height of Dog, mm

// Global phase clock for continuous gaits (0.0 to 1.0)
static float gait_phase = 0.0f;

static long map(long x, long in_min, long in_max, long out_min, long out_max);
static int angleToPulse(int ang);

// Interpolation function to map angles to pulse widths
static long map(long x, long in_min, long in_max, long out_min, long out_max) {
  return (x - in_min) * (out_max - out_min) / (in_max - in_min) + out_min;
}

// Helper function to map angles to PWM pulses
static int angleToPulse(int ang) {
  int pulse = map(ang, 0, 270, SERVO_MIN, SERVO_MAX);
  return pulse;
}

// Initialize all legs
void LegIK_HardwareInit(void) {
    LegIK_Init(&legFrontLeft, FL_SERVO_CENTER_HIP, FL_SERVO_CENTER_FEMUR, FL_SERVO_CENTER_TIBIA, CH_FL_HIP, CH_FL_FEMUR, CH_FL_TIBIA, true, true);
    LegIK_Init(&legFrontRight, FR_SERVO_CENTER_HIP, FR_SERVO_CENTER_FEMUR, FR_SERVO_CENTER_TIBIA, CH_FR_HIP, CH_FR_FEMUR, CH_FR_TIBIA, true, false);
    LegIK_Init(&legBackLeft, BL_SERVO_CENTER_HIP, BL_SERVO_CENTER_FEMUR, BL_SERVO_CENTER_TIBIA, CH_BL_HIP, CH_BL_FEMUR, CH_BL_TIBIA, false, true);
    LegIK_Init(&legBackRight, BR_SERVO_CENTER_HIP, BR_SERVO_CENTER_FEMUR, BR_SERVO_CENTER_TIBIA, CH_BR_HIP, CH_BR_FEMUR, CH_BR_TIBIA, false, false);
}

void setServoAngle(int channel, float angle) {
  // Constraint for safety
  if (angle < 0.0f) angle = 0.0f;
  if (angle > 270.0f) angle = 270.0f;
  
  // Create mapping with extra precision to reduce integer float rounding loss
  long pulse = map((long)(angle * 100.0f), 0, 27000, SERVO_MIN, SERVO_MAX);
  PCA9685_WriteMicroseconds((uint8_t)channel, (uint16_t)pulse);
}

void updateLeg(LegIK_t *leg, float x, float y, float z) {
  if (LegIK_Calculate(leg, x, y, z)) {
    float h = LegIK_GetHipServoAngle(leg);
    float f = LegIK_GetFemurServoAngle(leg);
    float t = LegIK_GetTibiaServoAngle(leg);
    setServoAngle(LegIK_GetHipServoChannel(leg), h);
    setServoAngle(LegIK_GetFemurServoChannel(leg), f);
    setServoAngle(LegIK_GetTibiaServoChannel(leg), t);
  }
}

void standingPose(void) {
    float back_x = 0;
    float front_x = 0;
    float back_z = 160;
    float front_z = 160;
    float y = currentY; // The leg equations use absolute Y

    updateLeg(&legFrontLeft, front_x, y, front_z);
    updateLeg(&legFrontRight, front_x, y, front_z);
    updateLeg(&legBackLeft, back_x, y, back_z);
    updateLeg(&legBackRight, back_x, y, back_z);
}

void crouchingPose(void) {
    float back_x = 0;
    float front_x = 0;
    float back_z = 100;
    float front_z = 100;
    float y = currentY; 

    updateLeg(&legFrontLeft, front_x, y, front_z);
    updateLeg(&legFrontRight, front_x, y, front_z);
    updateLeg(&legBackLeft, back_x, y, back_z);
    updateLeg(&legBackRight, back_x, y, back_z);
}

void heelingPose(void) {
    float back_x = -20;
    float front_x = -20;
    float back_z = 120;
    float front_z = 180;
    float y = currentY; 

    updateLeg(&legFrontLeft, front_x, y, front_z);
    updateLeg(&legFrontRight, front_x, y, front_z);
    updateLeg(&legBackLeft, back_x, y, back_z);
    updateLeg(&legBackRight, back_x, y, back_z);
}

void unisonGait(void) {
  const int Z_BASE = 180;    
  const int STEP_HEIGHT = 60; 
  const int INTERPOLATION_INCREMENT = 2;
  const int GAIT_X_MAX = 80;
  const int GAIT_X_MIN = -80;
  
  // SWING PHASE
  for (float i = GAIT_X_MIN; i < GAIT_X_MAX; i += INTERPOLATION_INCREMENT) {
    float angle = ( (i - GAIT_X_MIN) / (GAIT_X_MAX - GAIT_X_MIN) ) * 3.14159f;
    int offsetZ = sinf(angle) * STEP_HEIGHT;
    int curZ = Z_BASE - offsetZ;
    updateLeg(&legFrontLeft, i, currentY, curZ);
    updateLeg(&legFrontRight, i, currentY, curZ);
    updateLeg(&legBackLeft, i, currentY, curZ);
    updateLeg(&legBackRight, i, currentY, curZ);
    osDelay(10); // Added small task yield for gait speed
  }

  // STANCE PHASE
  for (int i = GAIT_X_MAX; i > GAIT_X_MIN; i -= INTERPOLATION_INCREMENT) {
    updateLeg(&legFrontLeft, i, currentY, Z_BASE); 
    updateLeg(&legFrontRight, i, currentY, Z_BASE);
    updateLeg(&legBackLeft, i, currentY, Z_BASE);
    updateLeg(&legBackRight, i, currentY, Z_BASE);
    osDelay(10);
  }
}

void stepGait(void) {
  const int Z_BASE = 180;    
  const int STEP_HEIGHT = 50; 
  const int INTERPOLATION_INCREMENT = 2; 
  const int GAIT_X_MAX = 20;
  const int GAIT_X_MIN = -20;
  const float TOTAL_X_DIST = GAIT_X_MAX - GAIT_X_MIN;

  // --- HALF CYCLE 1 ---
  for (float i = GAIT_X_MIN; i <= GAIT_X_MAX; i += INTERPOLATION_INCREMENT) {
    float progress = (i - GAIT_X_MIN) / TOTAL_X_DIST; 
    float angle = progress * 3.14159f; 
    int offsetZ = sinf(angle) * STEP_HEIGHT;
    int swingZ = Z_BASE - offsetZ;
    float swingX = i; 
    
    float stanceX = GAIT_X_MAX - (i - GAIT_X_MIN); 
    int stanceZ = Z_BASE;

    updateLeg(&legFrontRight, stanceX, currentY, stanceZ);
    updateLeg(&legBackLeft, stanceX, currentY, stanceZ);
    updateLeg(&legFrontLeft, swingX, currentY, swingZ);
    updateLeg(&legBackRight, swingX, currentY, swingZ);
    osDelay(15);
  }

  // --- HALF CYCLE 2 ---
  for (float i = GAIT_X_MIN; i <= GAIT_X_MAX; i += INTERPOLATION_INCREMENT) {
    float progress = (i - GAIT_X_MIN) / TOTAL_X_DIST;
    float angle = progress * 3.14159f;
    int offsetZ = sinf(angle) * STEP_HEIGHT;
    int swingZ = Z_BASE - offsetZ;
    float swingX = i;
    
    float stanceX = GAIT_X_MAX - (i - GAIT_X_MIN);
    int stanceZ = Z_BASE;
    
    updateLeg(&legFrontRight, swingX, currentY, swingZ);
    updateLeg(&legBackLeft, swingX, currentY, swingZ);
    updateLeg(&legFrontLeft, stanceX, currentY, stanceZ);
    updateLeg(&legBackRight, stanceX, currentY, stanceZ);
    osDelay(15);
  }
}
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

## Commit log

2025-11-10 Working on femur
    [Femur.SLDPRT, Femur_Test.SLDPRT, Femur_Test.STL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]
2025-11-10 Mostly done femur
    [Femur - V1.SLDPRT, Femur.SLDPRT, Femur_Inside.SLDPRT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]
2025-11-17 Done femur
    [Femur_Inside.SLDPRT, Femur_Inside.STL, Femur_Inside_old.SLDPRT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]
2025-11-19 Fixing femur
    [Femur_Inside.SLDPRT, Femur_Inside_V1.SLDPRT, Femur_Inside_V1.STL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]
2025-11-21 Working on tibia
    [Femur_Inside.SLDPRT, Femur_Outside.SLDPRT, Leg_Assembly.SLDASM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]
2025-11-22 Tibia in progress
    [Bellcrank.SLDPRT, Femur_Inside.SLDPRT, Femur_Outside.SLDPRT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]
2025-11-23 Almost done main leg
    [Bellcrank.SLDPRT, Femur_Inside_V3.STL, Femur_Outside_V3.STL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]
2025-11-24 Finished bellcrank
    [Bellcrank.SLDPRT, Bellcrank_V1.SLDPRT, Bellcrank_v2.SLDPRT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]
2025-11-26 Updated servo arm size
    [Bellcrank.STL, Femur_Inside.SLDPRT, Femur_Inside.STL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]
2025-11-30 Foot mold
    [Bellcrank.STL, DS3235SG 35KG.STEP, Femur_Inside.STL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]
2025-11-30 Update naming
    [Foot.SLDPRT, Foot_Assembly.SLDASM, Foot_mold.SLDPRT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]
2025-12-01 Add leg servo holder
    [Leg_Assembly.SLDASM, Leg_servo_holder_2.SLDPRT, Leg_servo_holder_Part1.SLDPRT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]
2025-12-02 Almost done leg servo holder
    [Leg_Assembly.SLDASM, Leg_servo_holder_Part1.SLDPRT, Leg_servo_holder_Part2.SLDPRT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]
2025-12-11 Test code and fixed mold model
    [Foot_for_mold.SLDPRT, Foot_mold.SLDPRT, Foot_mold_assembly.SLDASM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]
2025-12-11 Moved stl files
    [Foot_mold_bottom_side.STL, Foot_mold_top_side.STL]
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2025-12-12 Add Control board
    [LED_resistors.xlsx, Orion-Control-Board.kicad_pcb, Orion-Control-Board.kicad_sch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]
2025-12-12 Add linear rail design
    [2by4.SLDPRT, 2x2.SLDPRT, 608-2RS Skate Board Ball Bearing.step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]
2025-12-12 Initial power board
    [Orion-Power-Board.kicad_pcb, Orion-Power-Board.kicad_sch]
2025-12-13 Design IMU, Voltage Sensor, and Driver circuits
    [LED_resistors.xlsx, Orion-Control-Board.kicad_sch]
2025-12-13 Add lipo tester and LTC extender
    [Orion-Control-Board.kicad_pcb, Orion-Control-Board.kicad_sch]
2025-12-13 Power board
    [Orion-Power-Board.kicad_pcb, Orion-Power-Board.kicad_sch]
2025-12-14 Complete Schematic - Add STM32
    [Compute.kicad_sch, I2C Resistor calculator.xlsx, Orion-Control-Board.kicad_pcb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]
2025-12-14 Update JLCPCB rules
    [Compute.kicad_sch, Orion-Control-Board.kicad_pcb, Orion-Control-Board.kicad_sch]
2025-12-14 Done layout of power board
    [Orion-Power-Board.kicad_pcb, Orion-Power-Board.kicad_sch]
2025-12-14 Update symbols
    [Compute.kicad_sch, Orion-Control-Board.kicad_pcb, Orion-Control-Board.kicad_sch]
2025-12-14 Route IMU and Servo Driver
    [Compute.kicad_sch, Orion-Control-Board.kicad_pcb, Orion-Control-Board.kicad_sch]
2025-12-14 Update power board
    [Orion-Power-Board.kicad_pcb, Orion-Power-Board.kicad_sch]
2025-12-14 Route more
    [Compute.kicad_sch, Orion-Control-Board.kicad_pcb, Orion-Control-Board.kicad_sch]
2025-12-14 Route most traces
    [Compute.kicad_sch, Orion-Control-Board.kicad_pcb]
2025-12-14 Almost finished power board
    [Orion-Power-Board.kicad_pcb, Orion-Power-Board.kicad_sch]
2025-12-14 Route all except voltage sensor
    [Orion-Control-Board.kicad_pcb, Orion-Control-Board.kicad_sch]
2025-12-15 Finished power board
    [Orion-Power-Board.kicad_pcb, Orion-Power-Board.kicad_sch]
2025-12-15 Finish Control board
    [Orion-Control-Board.kicad_pcb]
2025-12-15 Round slot outline
    [Orion-Control-Board.kicad_pcb]
2025-12-15 Review Power board.
    [Orion-Control-Board.kicad_pcb, Orion-Power-Board.kicad_pcb, Orion-Power-Board.kicad_sch]
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2025-12-17 Made 2 parts, attempting to fix assembly
    [Body_side.SLDPRT, Leg_servo_holder_Part1.SLDPRT]
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2025-12-18 Add screen step model
    [Compute.kicad_sch, Orion-Control-Board.kicad_sch]
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2025-12-19 Add Jetson and PCB models
    [Orin_nano_case_bottom.3MF, Orin_nano_case_main_No_CAN_Holes.3MF, Orion-Power-Board.SLDASM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]
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2025-12-20 Trying to reduce assembly size
    [Body_Bottom.SLDPRT, Body_Front.SLDPRT, Body_Top_Front.SLDPRT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]
2025-12-21 Fixed solidworks assembly size
    [Body_Rear.SLDPRT]
2025-12-22 Fixed appearance of quadruped
    [Body_Bottom.SLDPRT, Body_Front.SLDPRT, Body_Rear.SLDPRT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]
2025-12-23 Fixing linkages and body
    [Body_Front.SLDPRT, Body_Top_Front.SLDPRT, Body_side.SLDPRT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]
2025-12-24 Fix linages
    [608-2RS Skate Board Ball Bearing.SLDPRT, Bellcrank.SLDPRT, Bellcrank.STL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]
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2025-12-25 Adjust for servo holder bearing
    [Bearing_6700-2RS_10x15x4.SLDPRT, Bearing_6704-2RS_20x27x4.SLDPRT, Body_Front.SLDPRT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]
2025-12-26 Fixed lidar model
    [Body_Top_Front.SLDPRT]
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2025-12-28 Bearing Dimensions from testing
    [BearingTest_10x15mm_Inner.SLDPRT, BearingTest_10x15mm_Inner.STL, BearingTest_10x15mm_Outer.SLDPRT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]
2025-12-28 Working on lidar and camera holder
    [Body_Top_Front.SLDPRT, Camera_Holder.SLDPRT, Lidar_Camera_Holder.SLDPRT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]
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2025-12-29 Fixed appearance
    [Bellcrank.SLDPRT, Bellcrank.STL, Bellcrank_Left.STL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]
2025-12-29 Fix rear top plate
    [Body_Top_Rear.SLDPRT, Body_side.SLDPRT]
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2025-12-29 Fixing bottom of body and adding rear shelf
    [Body_Bottom.SLDPRT, Body_Bottom_Coupler.SLDPRT, Body_side.3mf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]
2025-12-30 Fix Servo Clocking Script
    [Leg_Weight_Test.ino, Servo_Clocking.ino]
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2025-12-30 STL for bottom of body
    [Body_Bottom_Front.3mf, Body_Bottom_Front.STL, Body_Bottom_Rear.3mf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]
2025-12-31 Update back plate and print coupler
    [Body_Bottom_Coupler.3mf, Body_Bottom_Coupler.STL, Body_Rear.SLDPRT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]
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2025-12-31 Fixed front lid
    [Body_Top_Front.3mf, Body_Top_Front.SLDPRT, Body_Top_Front.STL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]
2025-12-31 Exported stl files for shelf and top lid
    [Bellcrank_Mirrored.STL, Body_Top_Rear.3mf, Body_Top_Rear.SLDPRT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]
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2025-12-31 Fixed lego servo holder parts
    [Leg_servo_holder.SLDPRT, Leg_servo_holder_Pt1.SLDPRT, Leg_servo_holder_Pt1_Mirrored.STL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]
2025-12-31 Exported camera holder stl
    [Camera_Holder.STL, Lidar_Holder_Legs.3mf]
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2026-01-01 Fix camera holder
    [Body_Top_Rear.3mf, Camera_Holder.3mf, Camera_Holder.SLDPRT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]
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2026-04-29 Updated libraries and fix led blink
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2026-05-01 Fixed hip if statements
    [LegIK.c, LegMotion.c]
2026-05-01 Fixed comment, and added linkage 3mf file
    [SmallLinkage.3mf]
2026-05-01 Fixed jitter by speeding up sin wave movement
    [pca9685.c]
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2026-05-25 Fix ths1 issues (connection uart)
    [stm32_bridge_node.py]
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2026-06-06 Fix bugs in button map
    [stm32_bridge_node.py]
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2026-06-17 Attempt to fix dog getting stuck in tilt position
    [LegIK.c]
2026-06-23 Fixed RTOS waving gait
    [LegMotion.c]
2026-06-23 Fix waving commands to set tibia angle.
    [LegMotion.c]
2026-06-23 Fixed reset cmd to not require deadman switch, fixed tilt up down cmd
    [stm32_bridge_node.py]
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2026-07-06 Fix build issues and dependency issues
    [cmd_mux_node.py, joystick_parser_node.py, params.yaml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]
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2026-07-12 Eyes strafing, broken sometimes
    [cmd_mux_node.py, params.yaml, roboeyes_node.py]
2026-07-14 Improve short linkage to be stronger
    [Leg_Assembly_Isolated.SLDASM, Leg_Assembly_Left.SLDASM, Leg_Assembly_Right.SLDASM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]
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2026-07-15 Major fixes to eyes code and update joystick for fandragon controller
    [cmd_mux_node.py, joystick_parser_node.py, params.yaml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]
2026-07-15 Blinking, idle, recentering bug fixes
    [joystick_parser_node.py, roboeyes_node.py]
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2026-07-15 Eyes no longer move when waving as desired
    [cmd_mux_node.py]
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2026-07-15 Fixed power on and off transitions
    [params.yaml, roboeyes_node.py]
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2026-07-19 Made button to easily make happy eyes, removed deadman switch, made normal mode first reset
    [joystick_parser_node.py]
2026-07-21 Add linkage and servo holder new 3mf files
    [Leg_servo_holder_Pt2_Only.3mf, Long_Linkages.3mf]
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2026-08-08 Fixed transmit issue by enabling usart1 global interrupt
    [Orion.ioc]
2026-08-08 Fix jetson side package
    [stm32_bridge_node.py]
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2026-08-08 Replace wave with heel
    [joystick_parser_node.py]
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2026-08-16 Fix urdf limits and upadte launch
    [robot_description.urdf]
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2026-08-17 Fixing origin
    [Body_Rear.SLDPRT, Leg_Assembly_Left.SLDASM, Leg_Assembly_Right.SLDASM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]
2026-08-18 Urdf now has proper angles
    [robot_description_v2.urdf]
2026-08-18 Fix laser transform
    [robot_description_v2.urdf]
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2026-08-18 Fix urdf to have proper angles from stm
    [robot_description.urdf]
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2026-09-01 Add rl urdf base files
    [5_5inch-hdmi-amoled.SLDASM, 5_5inch-hdmi-amoled.SLDPRT, Body_Bottom.SLDPRT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]
2026-09-02 Add robot usd for training
    [back_left_link_1.STL, back_left_link_2.STL, back_left_link_3.STL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]
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
